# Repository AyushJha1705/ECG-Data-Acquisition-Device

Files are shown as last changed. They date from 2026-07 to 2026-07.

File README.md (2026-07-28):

# PCB Prototype of ECG Data Acquisition System

## Overview
This repository contains the simulation files, schematic designs, and PCB fabrication files (Gerbers) for a robust, low-power Electrocardiogram (ECG) Data Acquisition (DAQ) system. The project was developed to accurately extract microvolt-level (0.5 mV to 5 mV) ECG signals from noisy environments and amplify them for analog-to-digital conversion (ADC).

## Hardware Architecture
The Analog Front-End (AFE) utilizes a multi-stage filtering and amplification process to isolate the ECG signal from biological and environmental interference:

*   **Instrumentation Amplifier (InAmp):** Uses an AD620 IC to provide a high Common-Mode Rejection Ratio (CMRR) of over 100 dB. This stage extracts the raw ECG signal while actively filtering out 50Hz power-line interference.
*   **High Pass Filter (HPF):** Implemented using a TL074 JFET-input Quad Op-Amp in a 2nd order Sallen-Key topology. With a cutoff frequency set at 0.01 Hz, this stage removes severe DC offsets (up to 300mV) caused by the skin-electrode interface and mitigates baseline wander from patient respiration.
*   **Gain Stage:** Utilizes another TL074 op-amp to amplify the signal by a factor of 15, ensuring the waveform reaches an ADC-processable magnitude without rail saturation.
*   **Low Pass Filter (LPF):** A 6th order Butterworth filter (Sallen-Key topology) with a sharp 120 dB/decade roll-off and a cutoff frequency of 75 Hz. This aggressively filters out high-frequency electromyographic (EMG) muscle noise and electronic interference.
*   **Total System Gain:** The staggered gain across all stages (InAmp: 5, HPF: 1.586, Gain Stage: 15, LPF: 4.22) yields a net system gain of 502, safely scaling the 1mV signal to an ADC-compatible range centered on a 2V offset.

## Simulation & Validation
The circuit's functional integrity was rigorously simulated and verified using MicroCap software. 
*   **Datasets Used:** Tested against real-world clinical data from the MIT-BIH Arrhythmia Database (Datasets 100, 101) and the MIT-BIH Normal Sinus Rhythm Database (Datasets 16265, 16273).
*   **Noise Rejection:** Simulations confirm the successful rejection of introduced 150 Hz and 200 Hz sinusoidal noise, as well as the complete blocking of 300mV DC offsets without phase distortion or QRS complex degradation.

## PCB Layout & Fabrication
The physical prototype was designed and routed using KiCad, focusing on spatial optimization and noise rejection.
*   **Board Dimensions:** Compact 2-layer design measuring 43.5 mm x 75.5 mm.
*   **Routing Protocols:** Trace widths were set to 0.8 mm for power lines and 0.2 mm for signals. The board utilizes 45-degree bend routing to minimize signal integrity issues and reduce electromagnetic interference (EMI).
*   **Grounding & Bypassing:** The entire bottom layer (B.Cu) serves as a dedicated ground plane to provide a low-impedance return path. Unpolarized 0.1uF ceramic bypass capacitors are placed adjacent to all power pins to suppress high-frequency AC noise and prevent oscillation during fast switching transitions.

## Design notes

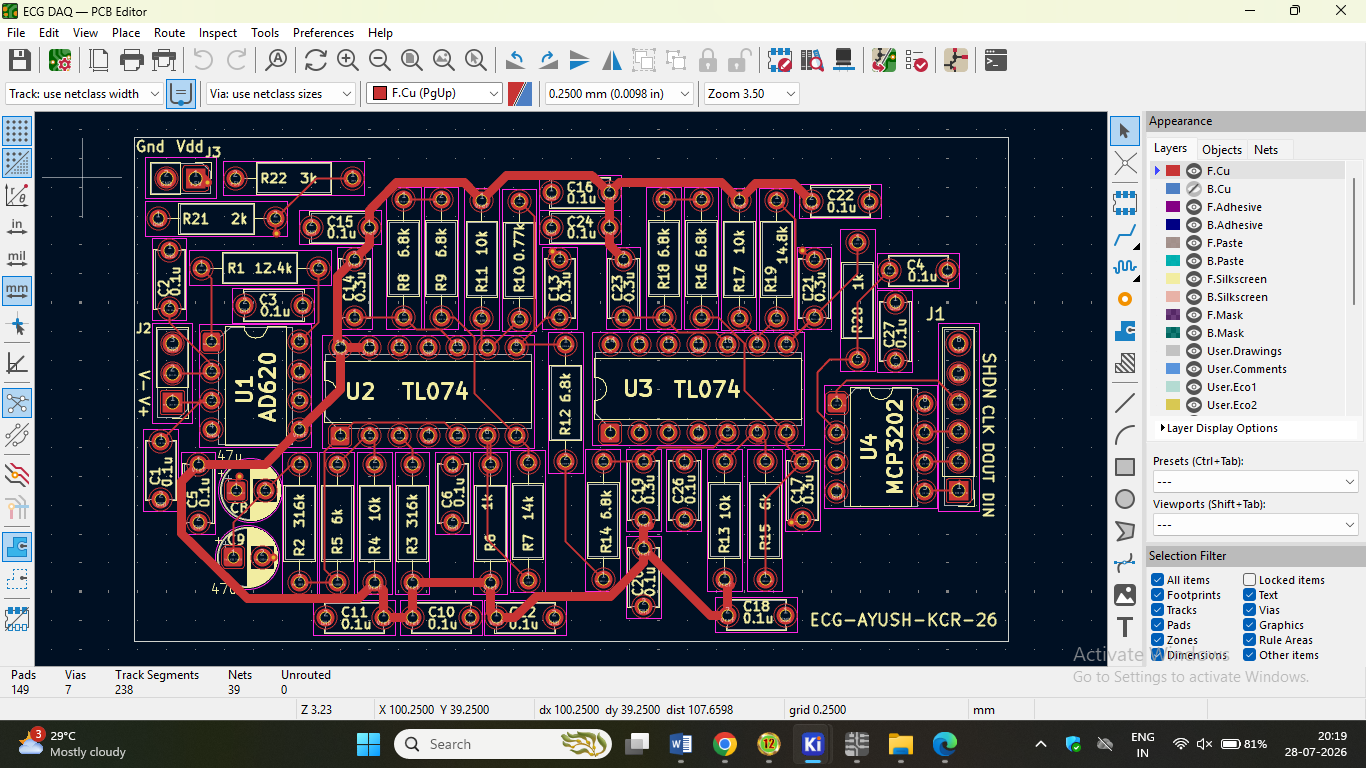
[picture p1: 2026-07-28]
Kicad_Design/PCB Layout.png

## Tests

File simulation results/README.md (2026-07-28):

# ECG DAQ Micro-Cap Simulation Results

The following simulations demonstrate the analog front-end filtering performance using various MIT-BIH datasets. The raw input signal is shown on the top graph, and the clean, filtered output is shown on the bottom graph.

### Dataset 100 (top), output (bottom):
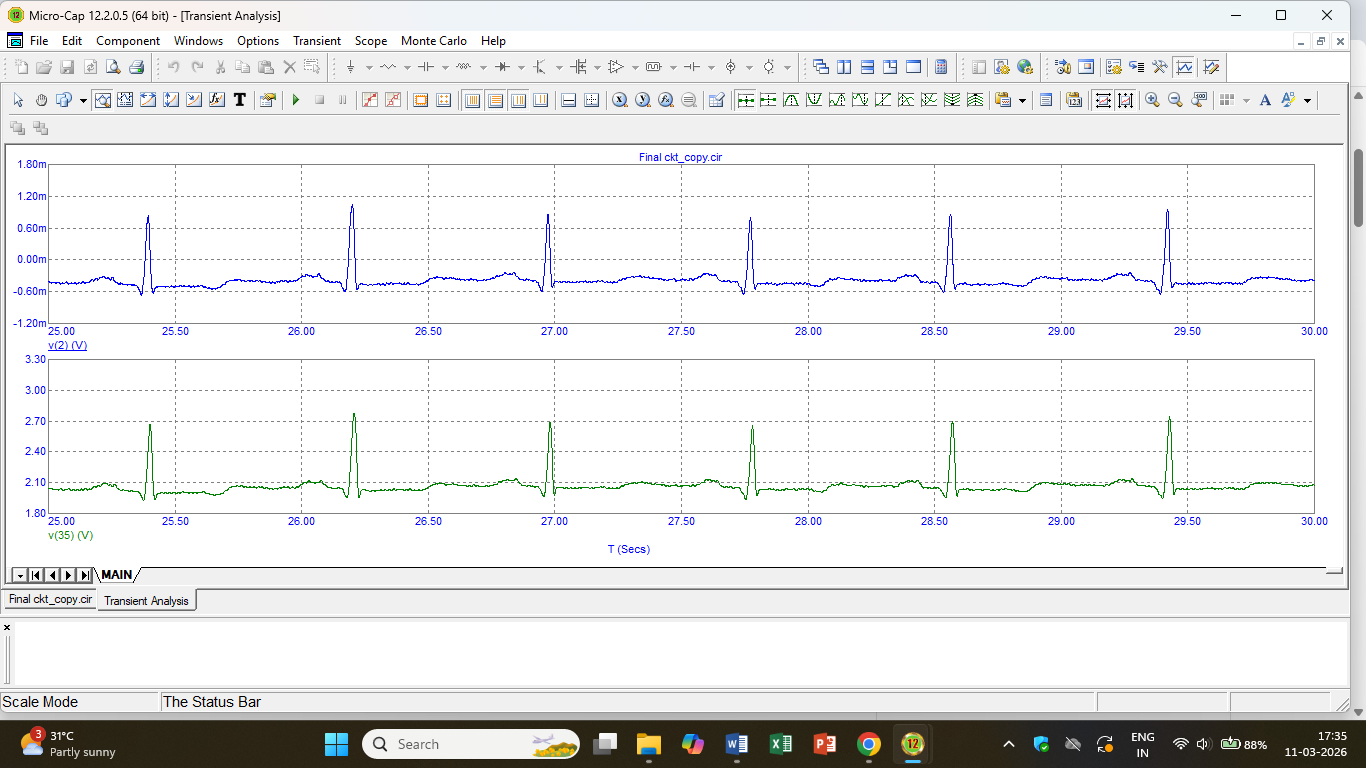
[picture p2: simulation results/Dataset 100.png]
Dataset 100


---

### Dataset 101 (top), output (bottom):
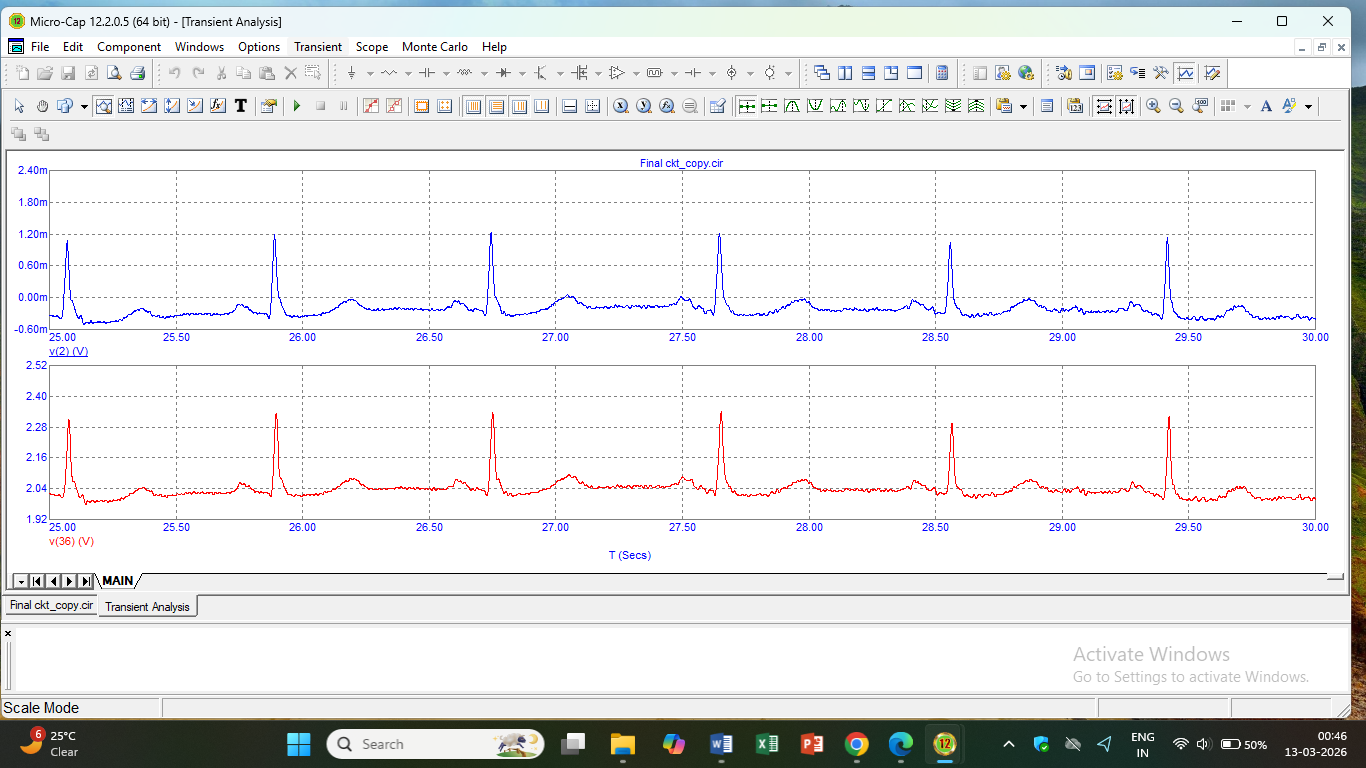
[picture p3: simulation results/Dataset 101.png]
Dataset 101


---

### Dataset 16265 (top), output (bottom):
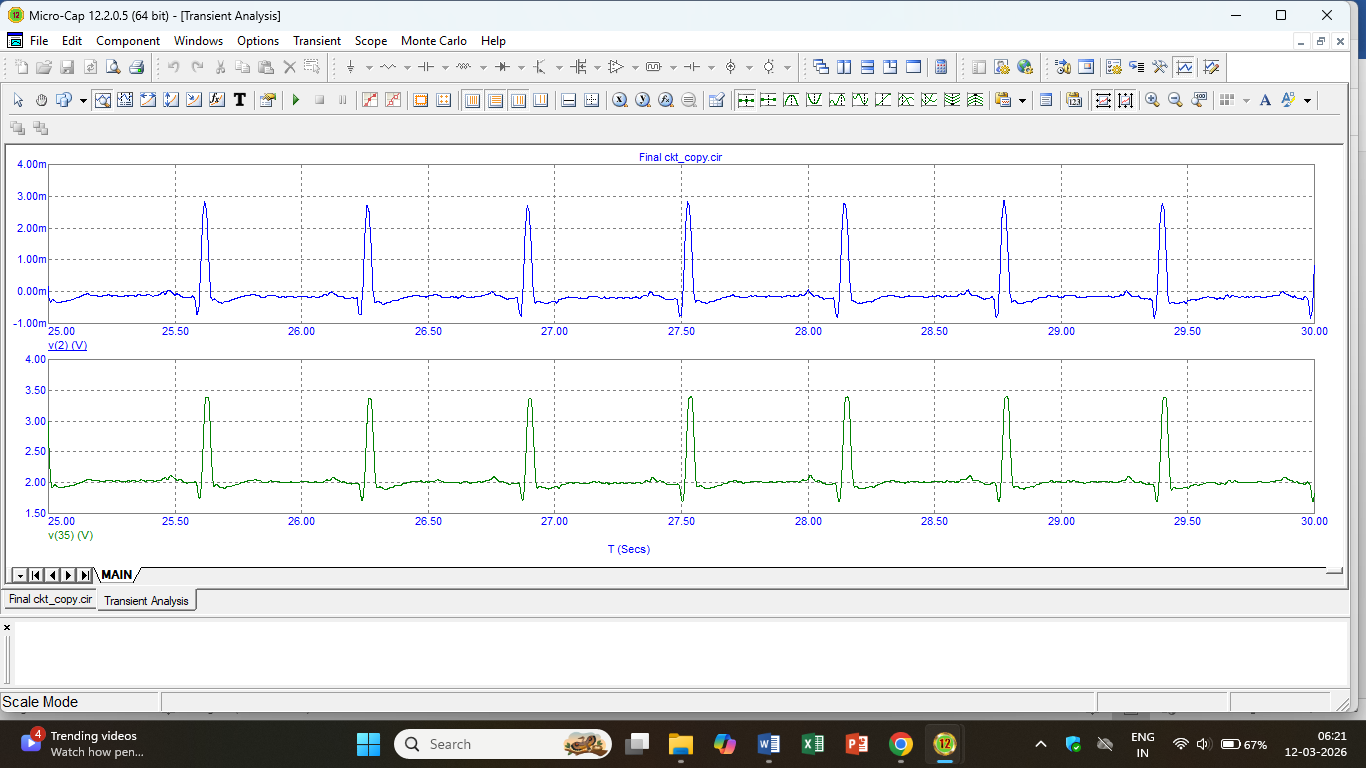
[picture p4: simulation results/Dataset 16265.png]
Dataset 16265


---

### Dataset 16273 (top), output (bottom):
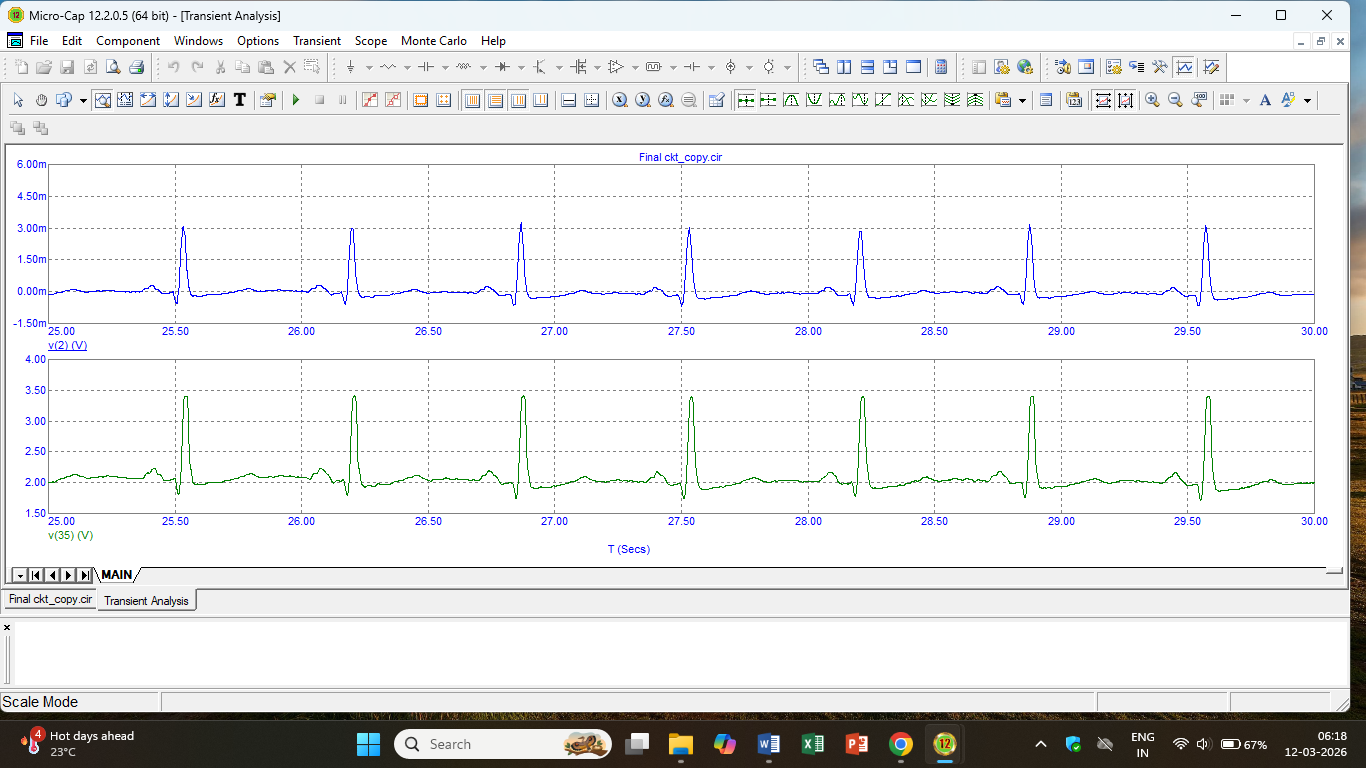
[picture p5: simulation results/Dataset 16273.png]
Dataset 16273


---

### Dataset 100 + 200Hz sinusoidal noise (top), output (bottom):
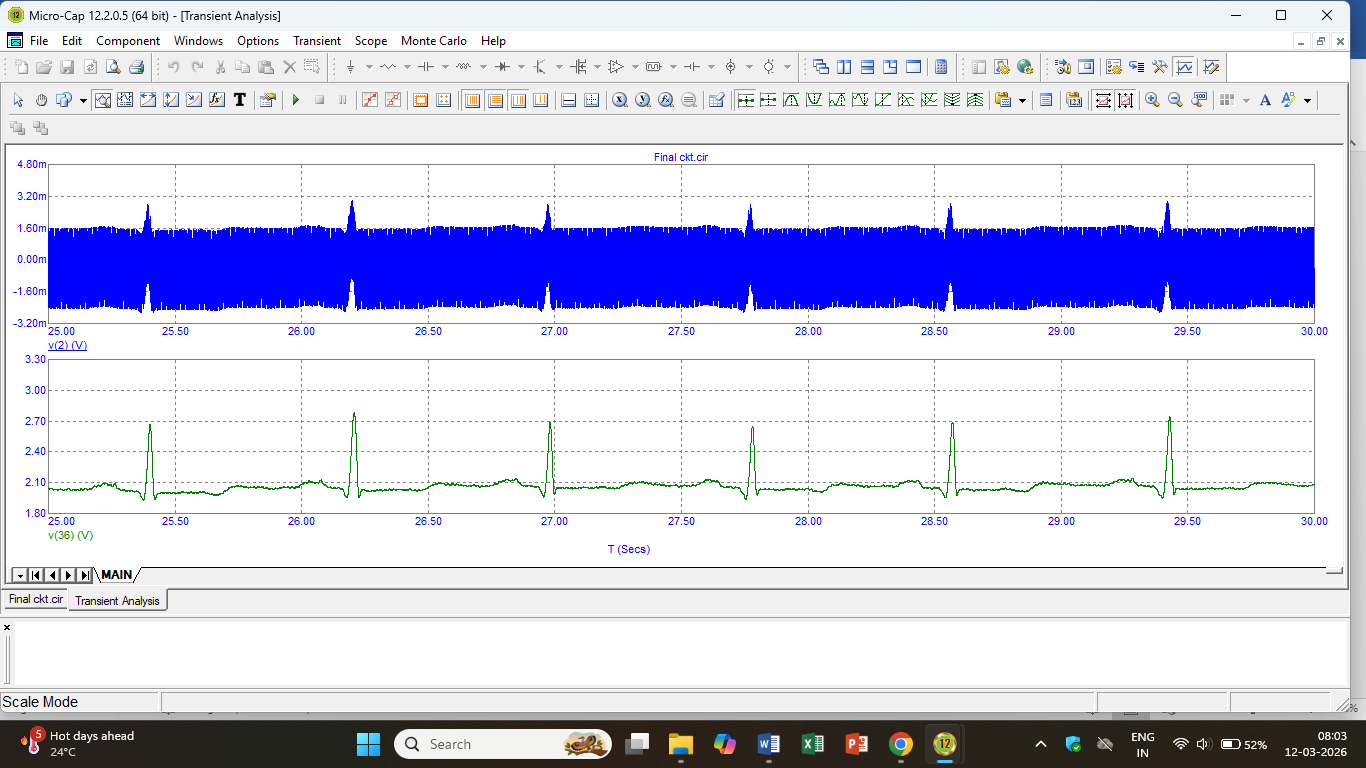
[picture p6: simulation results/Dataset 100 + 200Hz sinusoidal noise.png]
Dataset 100 + 200Hz sinusoidal noise


---

### Dataset 16273 + 200Hz sinusoidal noise (top), output (bottom):
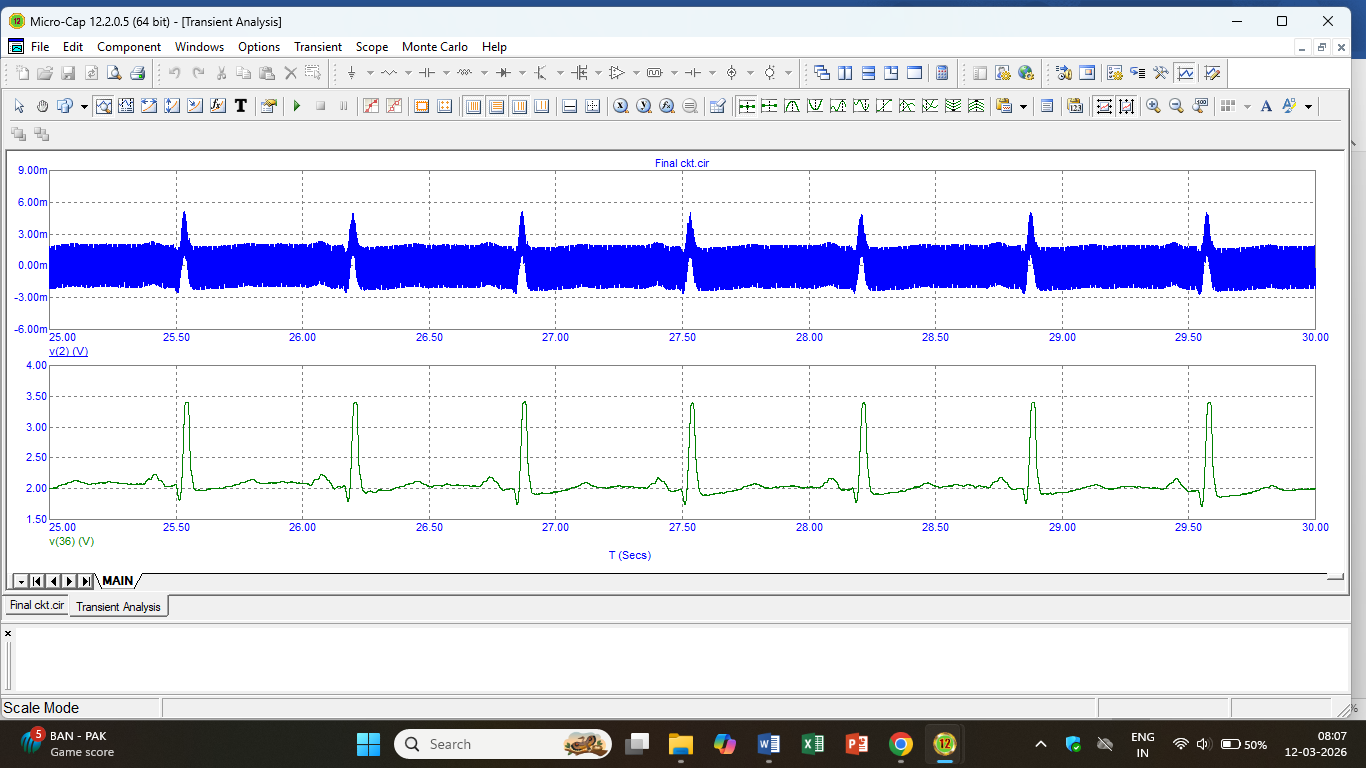
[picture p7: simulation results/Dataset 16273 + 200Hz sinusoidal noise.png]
Dataset 16273 + 200Hz sinusoidal noise


---

### Dataset 101 + 150Hz sinusoidal noise (top), output (bottom):
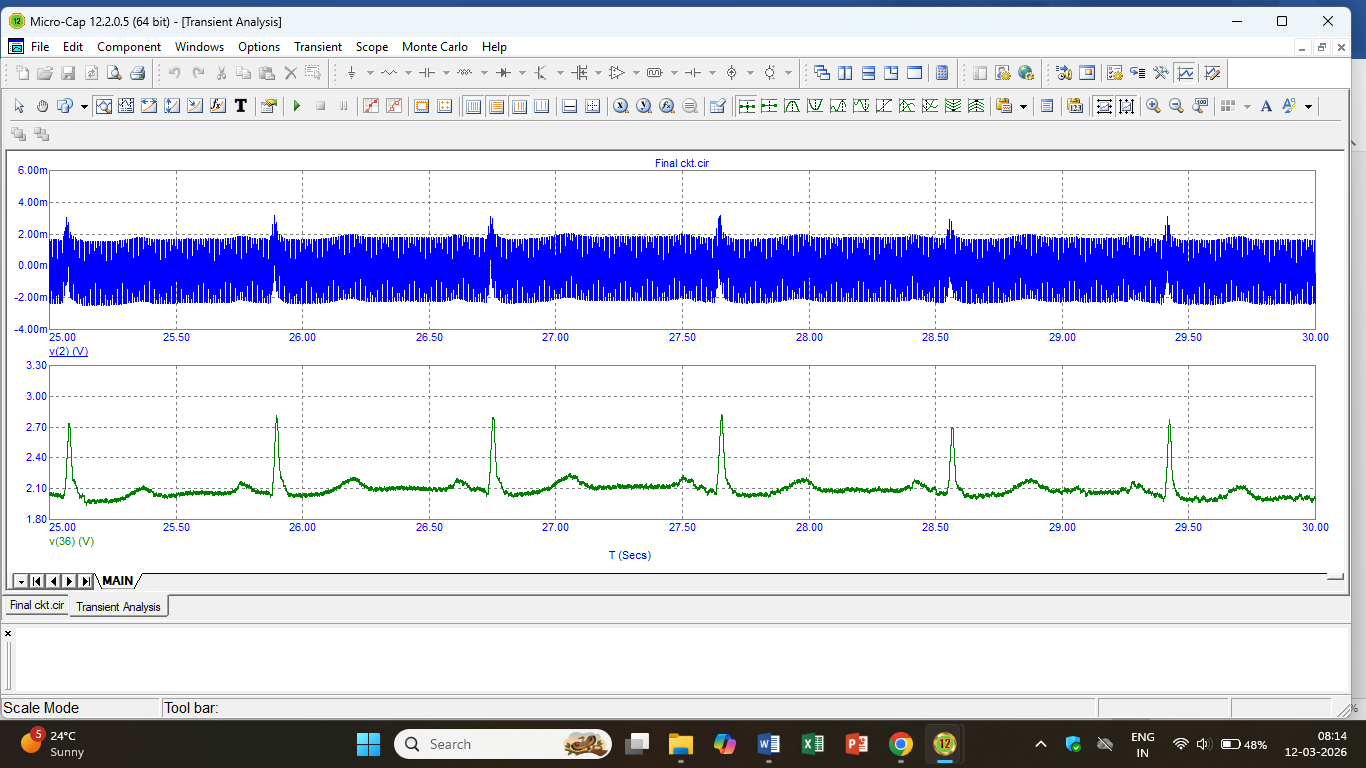
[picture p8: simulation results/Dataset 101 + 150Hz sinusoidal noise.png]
Dataset 101 + 150Hz sinusoidal noise


---

### Dataset 101+ 300mV DC offset (top), output (bottom):
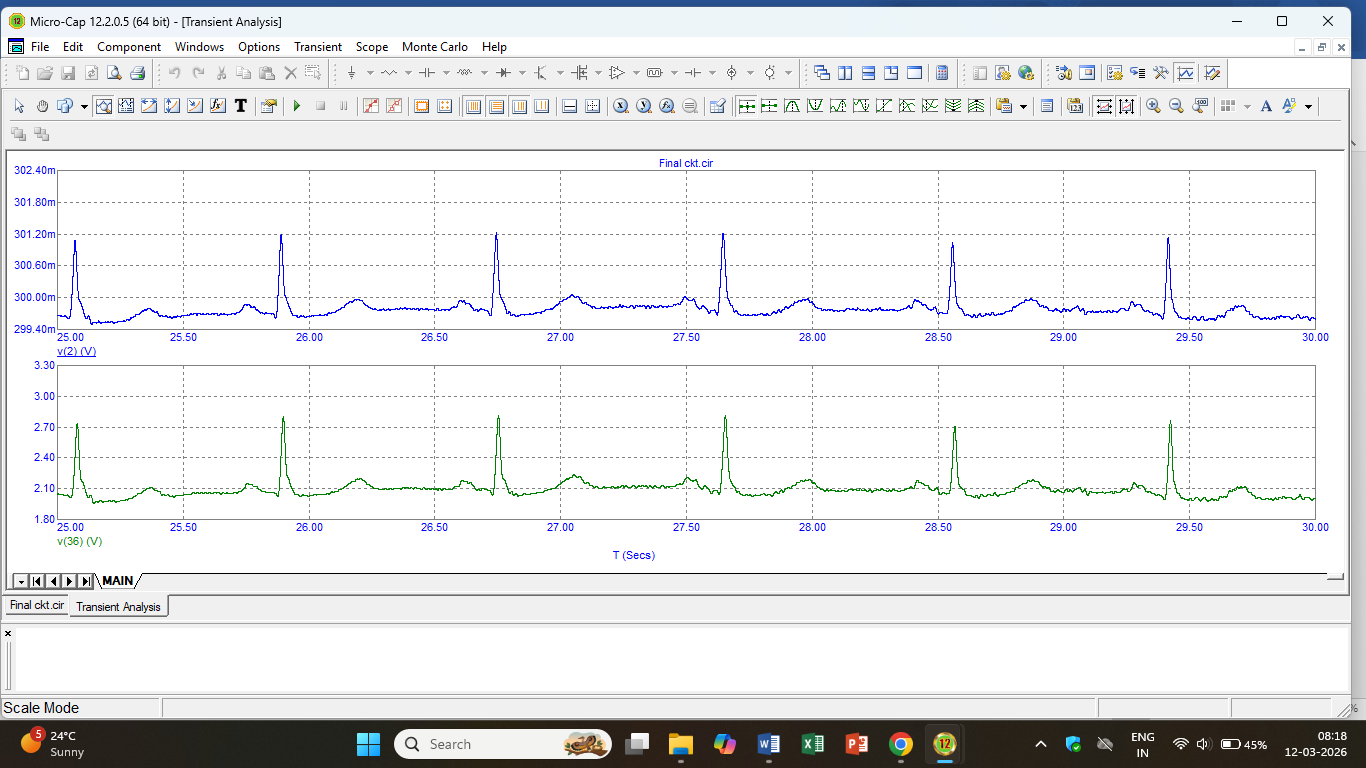
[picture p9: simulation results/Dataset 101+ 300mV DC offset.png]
Dataset 101+ 300mV DC offset


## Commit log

2026-07-28 Enhance README with project details and architecture
    Expanded the README to include project overview, hardware architecture, simulation details, and PCB layout information.
2026-07-28 Rename Final ckt_copy.cir to Circuit.cir
